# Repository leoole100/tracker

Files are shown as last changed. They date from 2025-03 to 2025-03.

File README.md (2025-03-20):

# Modular Tracking
Real-time detection, tracking, and control are fundamental to applications in robotics and automation. This project presents a modular, high-speed camera tracking system designed to explore detection, tracking, and control strategies by following a ping pong ball during gameplay. The system combines a Raspberry Pi Camera V2, stepper motors, and a Raspberry Pi 5, achieving real-time tracking at 200 fps through a modular Python-based software stack. The modular design and user-friendly interface make the system accessible for experimentation and learning, while its performance under controlled conditions demonstrates its potential for applications in robotics, sports analytics, and beyond.

Watch the video (https://youtu.be/diDA-3Ysf_I)
### [Watch this explanation on YouTube](https://youtu.be/diDA-3Ysf_I)

### Introduction

Real-time object tracking is a core challenge in computer vision and
robotics. Moving a camera to track a ping pong ball during gameplay
creates an interesting platform to explore and evaluate detection,
tracking, and control strategies. This is due to its unique combination
of steady ballistic flight interrupted by rapid, complex bounces at high
speeds.

To simplify the exploration of different strategies, the system is
designed with modularity and accessibility in mind. Each component is
built around high-level concepts, enabling users to experiment without
requiring an in-depth engineering background.

## Methods

The system is designed to track a ping pong ball in real time by moving
a camera dynamically. To achieve this, the project is broken down into
modular components, each addressing a specific aspect of the tracking
process.

### Hardware

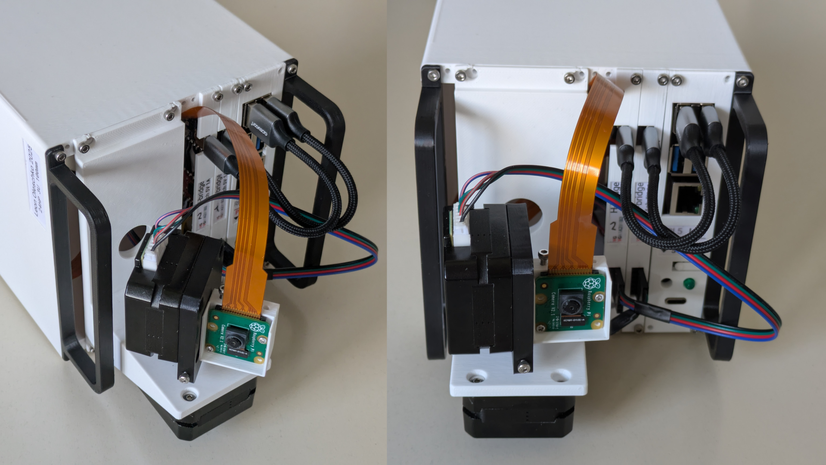
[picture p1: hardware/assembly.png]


The hardware components consists of a camera, motors, motor controllers
and a processing computer.\
The modules are designed as subrack modules and can be assembled as
shown in the figure above.

For the camera a Raspberry Pi Camera V2 is used, as with the
[picamera2](https://github.com/raspberrypi/picamera2) software stack it
supports a framerate of 200 Hz. A normal 30 Hz USB Webcam was tested to
be not sufficient.\
To move the camera 2 common stepper motors are mounted perpendicularly.
They are driven with field oriented controllers with the
[SimpleFOC](https://simplefoc.com/) firmware stack. They are connected
to the control computer using the Universal Serial Bus (USB).\
The chosen computer is a Raspberry Pi 5.

To power the components 9 V 3 A from a USB-C power supply are converted
to a 5 V 5 A bus for the computer and another 5 V 3 A bus for the
motors. Additionally the startup of the computer and the motors is
staggered. This was necessary to achieve stable operation.

### Software

The software architecture is designed to be modular, ensuring
flexibility and ease of experimentation. It is split into a camera
module, detector module, and motor module, with plans to add a tracker
module and controller module in the future. Each module can be
independently evaluated, modified, or replaced, allowing users to
experiment with different algorithms and configurations without
affecting the entire system.

The camera module configures the camera into a high frame rate mode and
fetches new frames.

The detector identifies the center of the ping pong ball in the image by
comparing each pixel's color $I(x,y)$ to a predefined reference color
$R$ in the Hue Saturation Luminance (HSL) color space. Testing showed
that HSL outperformed Luminance-AB (LAB). For each pixel, a weight $w$
is computed: $$w = \exp\left(- \frac{(I(x,y)-R)^2}{\sigma}\right)$$
Where $\sigma$ is the standard deviation of each channel in a reference
image of the ball. This function emphasizes pixels closely matching the
reference color while exponentially reducing the influence of outliers.
The color channels are then summed to get one weight for each pixel. The
location of the ball is determined by finding the position of the
maximum weight in the image.\
This process is efficiently implemented using
[numpy](https://numpy.org/), allowing the detector to process an
downsampled $80\times 60$ pixel frame in 3.6 ms. This high-speed
performance is critical for real-time tracking, ensuring the system can
keep up with the fast-moving ball during gameplay.

The tracker evaluates the detector's maximum weight $w_\text{max}$ to
determine if the detection is valid. Using hysteresis, it compares
$w_\text{max}$ to two thresholds $T_\text{heigh} > T_\text{low}$. If
$\omega_\text{max}>T_\text{heigh}$ it is valid; if
$\omega_\text{max}<T_\text{low}$ it is invalid. For values In between
$T_\text{low}<\omega_\text{max}<T_\text{heigh}$ the pervious state is
kept.\
This hysteresis-based approach ensures robust and smooth tracking, even
under challenging conditions.

The motors are moved based on the error, which is the angle between the
detected ball position and the center of the camera's field of view.
This error is scaled by a constant factor, producing a control signal
that drives the motors. This approach is known as a P-regulator
(proportional controller), where the motor response is directly
proportional to the error. While simple, this method provides effective
and responsive control for keeping the ball centered in the frame.

## Results

The simple detection and tracking approach works smoothly under
controlled lighting conditions and with a differently colored
background. However, in uncontrolled lighting environments, the
threshold for detection must be lowered to maintain sensitivity, which
introduces false positives. Despite this limitation, the system
demonstrates robust performance in ideal conditions, highlighting its
potential for applications where lighting can be managed.

## Conclusion

This project demonstrates the feasibility of a modular, high-speed
camera tracking system for following a ping pong ball in real time. By
combining a simple yet effective detection algorithm with a proportional
controller, the system achieves reliable performance under controlled
lighting conditions. The modular design allows for easy experimentation
with different strategies, making it a versatile platform for learning
and innovation in real-time object tracking.

Future work could focus on improving robustness in uncontrolled lighting
environments, such as by incorporating adaptive thresholding or machine
learning-based detection methods. Additionally, expanding the system to
include more advanced control strategies, like PID control or predictive
tracking, could further enhance performance. The platform also holds
potential for applications beyond ping pong, such as in robotics, sports
analytics, or automated surveillance, making it a valuable tool for both
education and research.

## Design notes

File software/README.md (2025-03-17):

To install requirements on raspberry pi os:
```bash
sudo apt install python3-flask-socketio python3-picamera2 python3-opencv python3-serial
```

To autostart create a system service:
```bash
sudo nano /etc/systemd/system/tacker.service
sudo systemctl enable tracker.service 
```

```
[Unit]
Description=Tracker
After=network.target

[Service]
Type=simple
ExecStart=/usr/bin/python3 /home/leon/tracker/software/main.py

[Install]
WantedBy=multi-user.target
```

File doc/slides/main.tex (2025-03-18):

\documentclass[aspectratio=169, 20pt]{beamer}
\input{preamble.tex}

\author{Leon Oleschko}
\date{\today}

\begin{document}
\begin{frame}
	\large
	\markieren{}{}{Modular Tracker}{following a ping pong ball}
	
	\vfill
	\normalsize
	Leon Oleschko\\
	\today
	
	\vfill
\end{frame}

\begin{frame}{Demo}
\end{frame}

\section{Hardware}
\slidefigure{../../figures/usb_webcam.png}
\slidefigure{../../figures/rpicam.png}
\slidefigure{../../figures/stepper.png}
\slidefigure{../../figures/stepper_mounted.png}
\slidefigure{../../figures/driver.png}
\slidefigure{../../figures/computer.png}
\slidefigure{../../figures/assembly.png}

\section{Software}
\slidefigure{../../figures/ball.png}
\begin{frame}
	\begin{gather*}
		\adjincludegraphics[height=3.5cm, valign=c]{../../figures/ball.png}
		= \\
		\adjincludegraphics[height=4cm, valign=c]{../../figures/rgb.png}
	\end{gather*}
\end{frame}

\begin{frame}
	\begin{align*}
		&\adjincludegraphics[height=3.5cm, valign=c]{../../figures/rgb.png}\\
		\Rightarrow\; &\adjincludegraphics[height=3.5cm, valign=c]{../../figures/hsv.png}
	\end{align*}
\end{frame}

\begin{frame}
	\begin{gather*}
		- \left(
				\adjincludegraphics[height=2cm, valign=c]{../../figures/hsv.png} - \adjincludegraphics[height=2cm, valign=c]{../../figures/mean.png}
		\right)^2\\
	= \adjincludegraphics[height=3cm, valign=c]{../../figures/diff.png}
	\end{gather*}
\end{frame}

\begin{frame}
	\begin{gather*}
		- \left|
			\frac{
				\adjincludegraphics[height=2cm, valign=c]{../../figures/diff.png}
			}{(\sigma_H, \sigma_S, \sigma_V)}
		\right|^2
	= \adjincludegraphics[height=4cm, valign=c]{../../figures/weight.png}
	\end{gather*}
\end{frame}

\begin{frame}
\end{frame}
\end{document}

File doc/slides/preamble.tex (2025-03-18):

\setbeamertemplate{navigation symbols}{}
\usepackage{xcolor}
\definecolor{seeblau}{HTML}{00A9E0}
\definecolor{seegrau}{HTML}{9AA0A7}

\definecolor{seeblau1}{HTML}{CCEEF9}
\definecolor{seeblau2}{HTML}{A6E1F4}
\definecolor{seeblau3}{HTML}{59C7EB}
\definecolor{seeblau4}{HTML}{00A9E0}
\definecolor{seeblau5}{HTML}{008ECE}

\setbeamercolor{title}{fg=seeblau}
\setbeamercolor{frametitle}{fg=seeblau}
\setbeamercolor{section in toc}{fg=seeblau}
\setbeamercolor{structure}{fg=seeblau}

\setbeamertemplate{footline}{%
	\begin{beamercolorbox}[sep=.25cm,wd=\paperwidth,leftskip=0.25cm,rightskip=0.25cm]{footlinecolor}
		\small
		% \textbf{\insertsection}\quad\insertsubsection
		% \hfill\insertframenumber
	\end{beamercolorbox}%
}

\usepackage[overridenote]{pdfpc}

\usepackage[english]{babel}
\parskip=20pt

\usepackage[sfdefault]{roboto}
\usepackage{libertinust1math}
\usefonttheme[onlymath]{serif}

\usepackage{ifthen, adjustbox}
\newcommand{\markieren}[4]{
	\ifthenelse{\equal{#1}{}}{}{\adjustbox{padding=3pt, bgcolor=seeblau1, margin=-1pt}{\strut{\sffamily\robotoMedium{#1}}}\\}
  \ifthenelse{\equal{#2}{}}{}{\adjustbox{padding=3pt, bgcolor=seeblau2, margin=-1pt}{\strut{\sffamily\robotoMedium{#2}}}\\}
	\ifthenelse{\equal{#3}{}}{}{\adjustbox{padding=3pt, bgcolor=seeblau3, margin=-1pt}{\strut{\sffamily\robotoMedium{#3}}}\\}
	\ifthenelse{\equal{#4}{}}{}{\adjustbox{padding=3pt, bgcolor=seeblau4, margin=-1pt}{\strut{\sffamily\robotoMedium{#4}}}}
}

\let\footnoterule\relax % removes bar
\setbeamertemplate{footnote}{
  \parindent 0em\noindent
  \raggedleft
  \usebeamercolor{footnote}\hbox to 0.8em{\hfil\insertfootnotemark}\tiny\insertfootnotetext\par%
}

\newcommand\blfootnote[1]{
	\let\thefootnote\relax\footnotetext{#1}
}

\usepackage[
	style=authortitle
]{biblatex}
\usepackage{ifthen}
\newcommand{\customcite}[2][]{
	\blfootnote{
		\emph{\citetitle{#2}}, \citeauthor*{#2}	\citeyear{#2}
		\ifthenelse{ \equal{#1}{} }{}{(#1)}
	}
}

\newcommand{\highlightcite}[2][]{
	\blfootnote{
		\color{seeblau}
		\small
		\emph{\citetitle{#2}}, \citeauthor*{#2}	\citeyear{#2}
		\ifthenelse{ \equal{#1}{} }{}{(#1)}
	}
}

\usepackage[ddmmyyyy]{datetime}
\renewcommand{\dateseparator}{.}

\usepackage{amsmath,amssymb,amsfonts,amsthm}

\usepackage{tikz}

\newcommand{\slidefigure}[1]{
{ % all template changes are local to this group.
\setbeamertemplate{navigation symbols}{}
\begin{frame}<article:0>[plain]
	\begin{tikzpicture}[remember picture,overlay]
		\node[at=(current page.center)] {
			\includegraphics[keepaspectratio,
								width=\paperwidth,
								height=\paperheight]{#1}
		};
	\end{tikzpicture}
	\end{frame}
}
}

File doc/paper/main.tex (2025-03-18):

\documentclass[
    parskip=half, 
    twoside=false,
    twocolumn=true,
    fontsize=12pt,
]{scrarticle}
\input{preamble.tex}

\begin{document}

\title{Modular Tracking}
\author{Leon Oleschko}
\date{\dotdate\today}

\twocolumn[{%
    \sffamily
    \huge
    \markieren{}{}{Modular Tracker}{following a ping pong ball}
    \vspace{.5 cm}\\
    \normalsize
    Leon Oleschko\\
    \dotdate\today
    \vspace{.5 cm}\\
    \normalfont
    \begin{abstract}
        Real-time detection, tracking, and control are fundamental to applications in robotics and automation. This project presents a modular, high-speed camera tracking system designed to explore detection, tracking, and control strategies by following a ping pong ball during gameplay. The system combines a Raspberry Pi Camera V2, stepper motors, and a Raspberry Pi 5, achieving real-time tracking at \SI{200}{Hz} through a modular Python-based software stack. The modular design and user-friendly interface make the system accessible for experimentation and learning, while its performance under controlled conditions demonstrates its potential for applications in robotics, sports analytics, and beyond.
    \end{abstract}
    \bigskip
}]

\subsection*{Introduction}
Real-time object tracking is a core challenge in computer vision and robotics. Moving a camera to track a ping pong ball during gameplay creates an interesting platform to explore and evaluate detection, tracking, and control strategies. This is due to its unique combination of steady ballistic flight interrupted by rapid, complex bounces at high speeds.

To simplify the exploration of different strategies, the system is designed with modularity and accessibility in mind. Each component is built around high-level concepts, enabling users to experiment without requiring an in-depth engineering background.

\section{Methods}
The system is designed to track a ping pong ball in real time by moving a camera dynamically. To achieve this, the project is broken down into modular components, each addressing a specific aspect of the tracking process. 

\subsection*{Hardware}
\begin{figure}
    \centering
    
    \caption{Mechanical assembly of all components.}
    \label{fig:assembly}
\end{figure}
The hardware components consists of a camera, motors, motor controllers and a processing computer.\\
The modules are designed as subrack modules and can be assembled as shown in \autoref{fig:assembly}.

For the camera a Raspberry Pi Camera V2 is used, as with the \href{https://github.com/raspberrypi/picamera2}{picamera2} software stack it supports a framerate of \SI{200}{Hz}.
A normal \SI{30}{Hz} USB Webcam was tested to be not sufficient.\\
To move the camera 2 common stepper motors are mounted perpendicularly.
They are driven with field oriented controllers with the \href{https://simplefoc.com/}{SimpleFOC} firmware stack.
They are connected to the control computer using the Universal Serial Bus (USB).\\
The chosen computer is a Raspberry Pi 5.

To power the components \SI{9}{V}~\SI{3}{A} from a USB-C power supply are converted to a \SI{5}{V}~\SI{5}{A} bus for the computer and another \SI{5}{V}~\SI{3}{A} bus for the motors.
Additionally the startup of the computer and the motors is staggered.
This was necessary to achieve stable operation.

\subsection*{Software}
The software architecture is designed to be modular, ensuring flexibility and ease of experimentation. It is split into a camera module, detector module, and motor module, with plans to add a tracker module and controller module in the future. Each module can be independently evaluated, modified, or replaced, allowing users to experiment with different algorithms and configurations without affecting the entire system.

The camera module configures the camera into a high frame rate mode and fetches new frames.

The detector identifies the center of the ping pong ball in the image by comparing each pixel's color $I(x,y)$ to a predefined reference color $R$ in the Hue Saturation Luminance (HSL) color space.
Testing showed that HSL outperformed Luminance-AB (LAB).
For each pixel, a weight $w$ is computed:
$$w = \exp\left(- \frac{(I(x,y)-R)^2}{\sigma}\right)$$
Where $\sigma$ is the standard deviation of each channel in a reference image of the ball.
This function emphasizes pixels closely matching the reference color while exponentially reducing the influence of outliers.
The color channels are then summed to get one weight for each pixel.
The location of the ball is determined by finding the position of the maximum weight in the image.\\
This process is efficiently implemented using \href{https://numpy.org/}{numpy}, allowing the detector to process an downsampled $80\times 60$ pixel frame in \SI{3.6}{ms}.
This high-speed performance is critical for real-time tracking, ensuring the system can keep up with the fast-moving ball during gameplay.

The tracker evaluates the detector's maximum weight $w_\text{max}$ to determine if the detection is valid.
Using hysteresis, it compares $w_\text{max}$ to two thresholds $T_\text{heigh} > T_\text{low}$.
If $\omega_\text{max}>T_\text{heigh}$ it is valid; if $\omega_\text{max}<T_\text{low}$ it is invalid.
For values In between $T_\text{low}<\omega_\text{max}<T_\text{heigh}$ the pervious state is kept.\\
This hysteresis-based approach ensures robust and smooth tracking, even under challenging conditions. 

The motors are moved based on the error, which is the angle between the detected ball position and the center of the camera's field of view. This error is scaled by a constant factor, producing a control signal that drives the motors. This approach is known as a P-regulator (proportional controller), where the motor response is directly proportional to the error. While simple, this method provides effective and responsive control for keeping the ball centered in the frame.

\section{Results}
The simple detection and tracking approach works smoothly under controlled lighting conditions and with a differently colored background. However, in uncontrolled lighting environments, the threshold for detection must be lowered to maintain sensitivity, which introduces false positives. Despite this limitation, the system demonstrates robust performance in ideal conditions, highlighting its potential for applications where lighting can be managed.

\section{Conclusion}
This project demonstrates the feasibility of a modular, high-speed camera tracking system for following a ping pong ball in real time. By combining a simple yet effective detection algorithm with a proportional controller, the system achieves reliable performance under controlled lighting conditions. The modular design allows for easy experimentation with different strategies, making it a versatile platform for learning and innovation in real-time object tracking.

Future work could focus on improving robustness in uncontrolled lighting environments, such as by incorporating adaptive thresholding or machine learning-based detection methods. Additionally, expanding the system to include more advanced control strategies, like PID control or predictive tracking, could further enhance performance. The platform also holds potential for applications beyond ping pong, such as in robotics, sports analytics, or automated surveillance, making it a valuable tool for both education and research.

\end{document}

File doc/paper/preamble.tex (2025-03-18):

\usepackage{xcolor}
\definecolor{seeblau}{HTML}{00A9E0}
\definecolor{seegrau}{HTML}{9AA0A7}

\definecolor{seeblau1}{HTML}{CCEEF9}
\definecolor{seeblau2}{HTML}{A6E1F4}
\definecolor{seeblau3}{HTML}{59C7EB}
\definecolor{seeblau4}{HTML}{00A9E0}
\definecolor{seeblau5}{HTML}{008ECE}

\usepackage{graphicx}
\usepackage{amsmath}
\usepackage{subcaption}
\usepackage{wrapfig}
\usepackage[english]{babel}
\usepackage{blindtext}
\usepackage{microtype}
\usepackage{siunitx}
\usepackage[utf8]{inputenc}
\usepackage{csquotes}
\usepackage{nicefrac}
\usepackage[T1]{fontenc}
\usepackage{amsfonts}
\usepackage{amssymb}
\usepackage{tikz}
\usepackage{parskip}

\usepackage{libertinus, libertinust1math}
\usepackage[sfdefault]{biolinum}
\usepackage{roboto}

\setkomafont{disposition}{\normalfont\sffamily}

% set margins
\usepackage{geometry}
\geometry{
	a4paper,
	left=2.5cm,
	right=2.5cm,
	top=2.5cm,
	bottom=2.5cm
}

% not recommended with KOMA-script
% make table of contents sans-serif
% \usepackage{tocloft}
% \renewcommand\cftchappagefont{\normalfont}
% \renewcommand\cftchapfont{\normalfont}
% \renewcommand\cftchappresnum{\bfseries}
% \renewcommand\cftchapaftersnum{}
% \renewcommand{\cftchapfont}{\sffamily}
% \renewcommand{\cftsecfont}{\sffamily}
% \renewcommand{\cftsubsecfont}{\sffamily}
% \renewcommand{\cftchappagefont}{\sffamily}
% \renewcommand{\cftsecpagefont}{\sffamily}
% \renewcommand{\cftsubsecpagefont}{\sffamily}

% caption
\usepackage{caption}
\captionsetup{
	% font={sf},
	labelfont={sf, bf, color=seeblau},
	labelsep=quad,
	labelformat=simple,
}

% links
\usepackage{hyperref}
\hypersetup{
	colorlinks=true,
	linkcolor=seeblau,
	citecolor=seeblau,
	urlcolor=seeblau,
	% hidelinks=true
}

% bibliography
\usepackage[
	style=numeric-comp, % comp = compressed 4,5,6,7 -> 4-7
	sorting=none,		% Sort by appearance
	% autocite = superscript,
	% backref=true,
	hyperref=true,
	url=true,
	maxbibnames=100
]{biblatex}

\usepackage{float}
% \floatplacement{figure}{h}
% \floatplacement{table}{H}

% loosen float placement rules
\renewcommand{\topfraction}{0.8}
\renewcommand{\bottomfraction}{.8}
\renewcommand{\textfraction}{0.1}
\renewcommand{\floatpagefraction}{.9}
% make floats less likely to be placed on a separate page
\setcounter{totalnumber}{9}
\setcounter{topnumber}{9}
\setcounter{bottomnumber}{9}

% decrease space between floats and text
\setlength{\textfloatsep}{0.25cm}
\setlength{\floatsep}{0.25cm}

% decrease space after disposition
\RedeclareSectionCommands[
	afterskip=1px
]{section, subsection, subsubsection}

\usepackage{adjustbox}

\usepackage{datetime}
\newdateformat{dotdate}{
	\twodigit{\THEDAY}.\twodigit{\THEMONTH}.\THEYEAR
}
\newdateformat{monthyeardate}{%
  \monthname[\THEMONTH] \THEYEAR}

% header and footer
\usepackage[
  markcase=noupper
]{scrlayer-scrpage}% activates pagestyle scrheadings automatically
\clearpairofpagestyles
\setkomafont{pageheadfoot}{\normalfont\sffamily}
\setkomafont{pagenumber}{\normalfont\sffamily}
% \chead*{\color{seegrau} Draft \dotdate\today}
\ofoot*{\pagemark}
\ohead*{\rightmark}

\usepackage{ifthen, adjustbox}
\newcommand{\markieren}[4]{
	\ifthenelse{\equal{#1}{}}{}{\adjustbox{padding=3pt, bgcolor=seeblau1, margin=-1pt}{\strut{\sffamily\robotoMedium{#1}}}\\}
  \ifthenelse{\equal{#2}{}}{}{\adjustbox{padding=3pt, bgcolor=seeblau2, margin=-1pt}{\strut{\sffamily\robotoMedium{#2}}}\\}
	\ifthenelse{\equal{#3}{}}{}{\adjustbox{padding=3pt, bgcolor=seeblau3, margin=-1pt}{\strut{\sffamily\robotoMedium{#3}}}\\}
	\ifthenelse{\equal{#4}{}}{}{\adjustbox{padding=3pt, bgcolor=seeblau4, margin=-1pt}{\strut{\sffamily\robotoMedium{#4}}}}
}

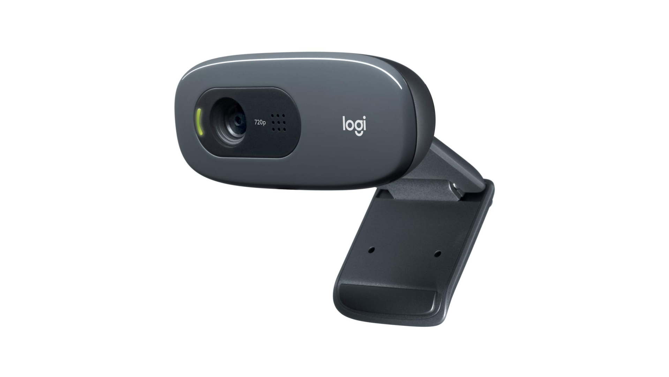
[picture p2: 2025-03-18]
figures/usb_webcam.png

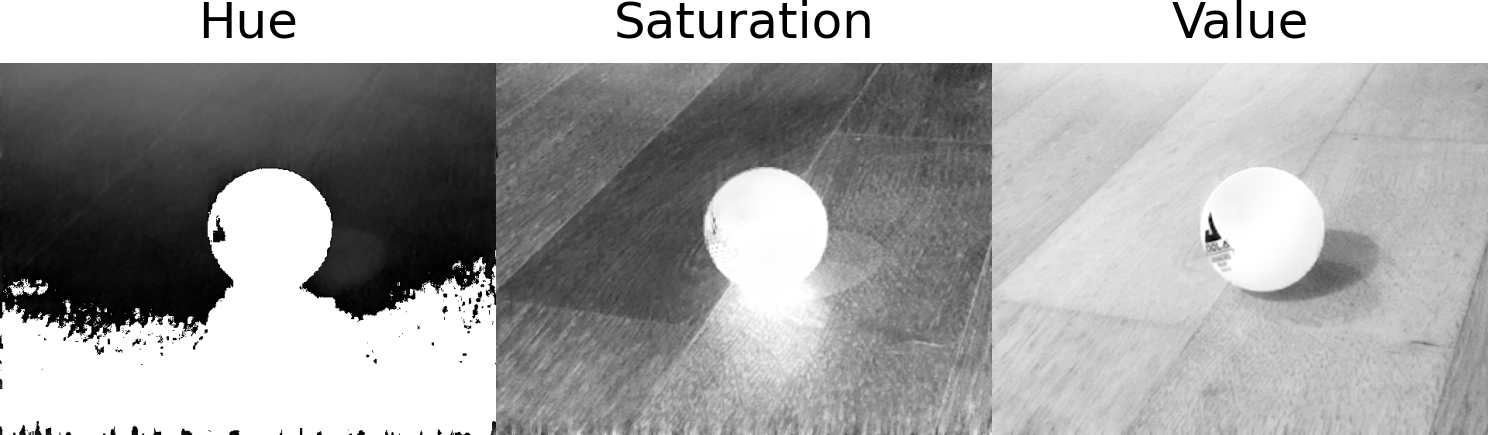
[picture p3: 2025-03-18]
figures/diff.png

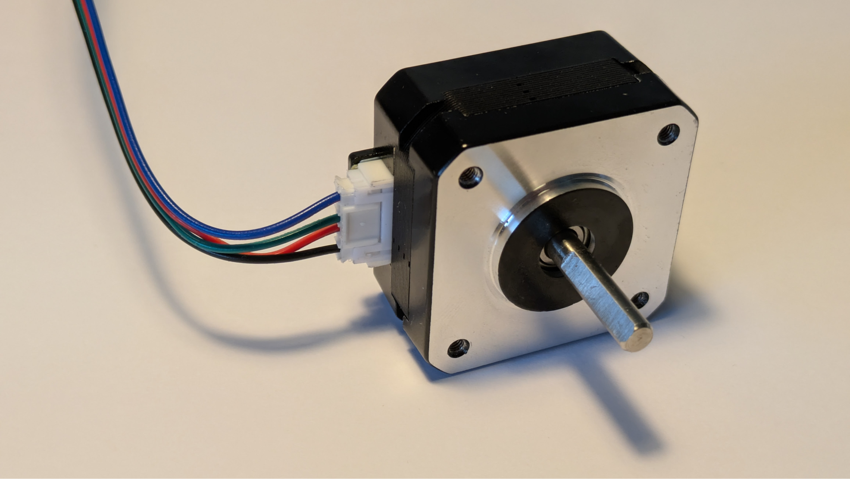
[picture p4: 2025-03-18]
figures/stepper.png

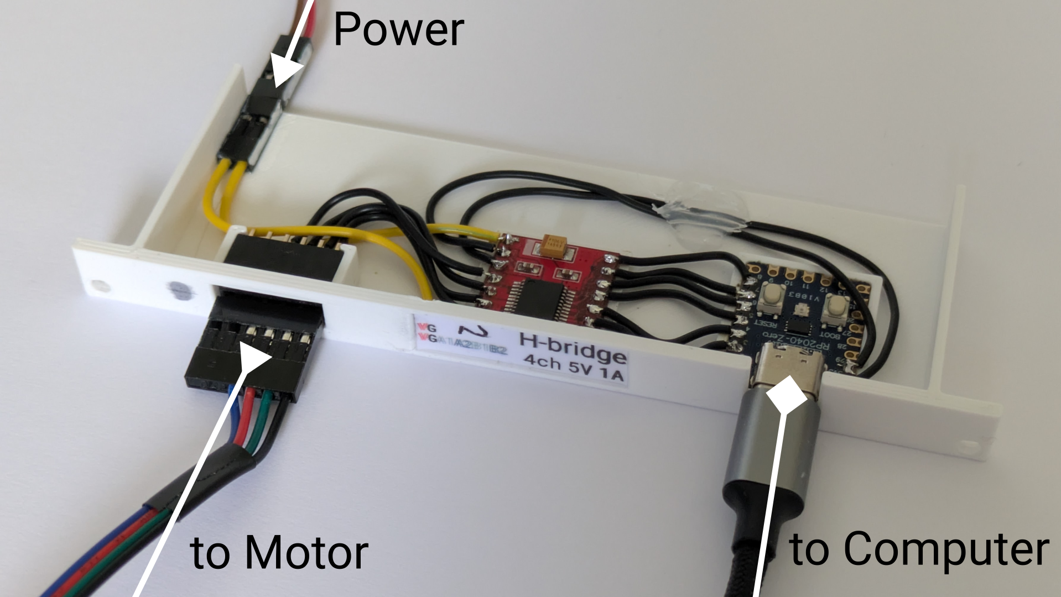
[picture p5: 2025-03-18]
figures/driver.png

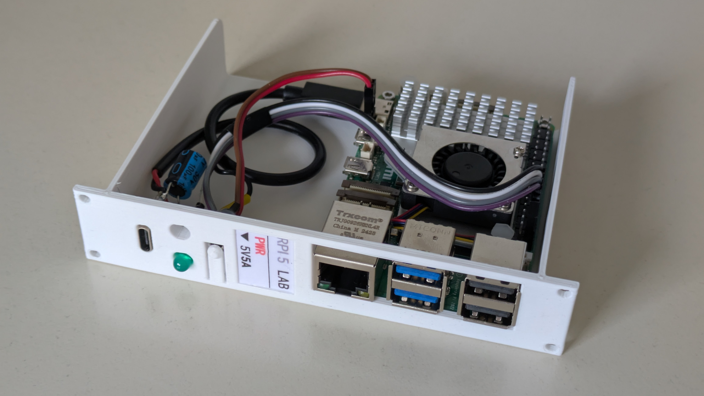
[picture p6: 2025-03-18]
figures/computer.png

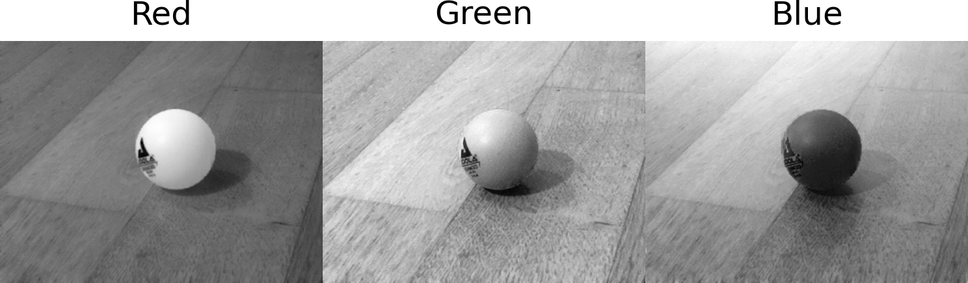
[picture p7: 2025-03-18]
figures/rgb.png

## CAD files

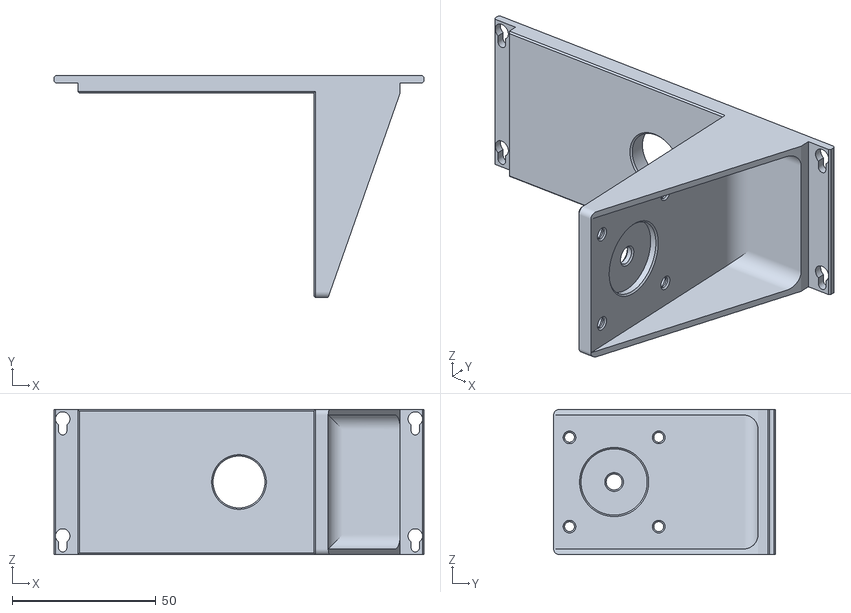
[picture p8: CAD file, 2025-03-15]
hardware/base-Body.stl
128.6 x 77.0 x 50.5

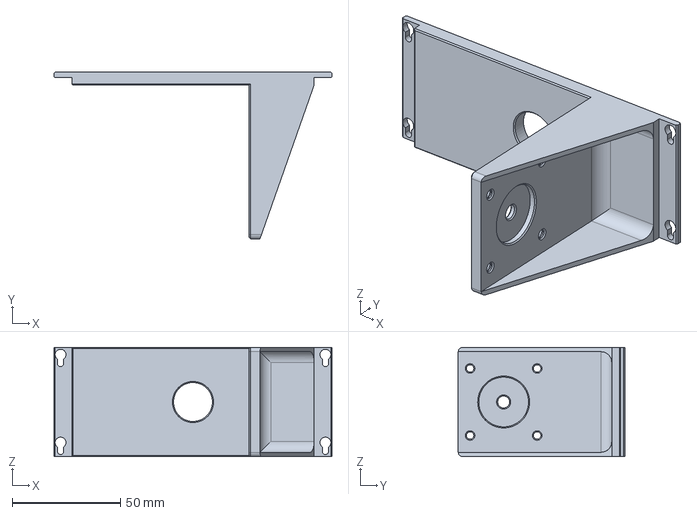
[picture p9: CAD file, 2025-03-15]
hardware/base.FCStd
128.6 x 77.0 x 50.5 mm

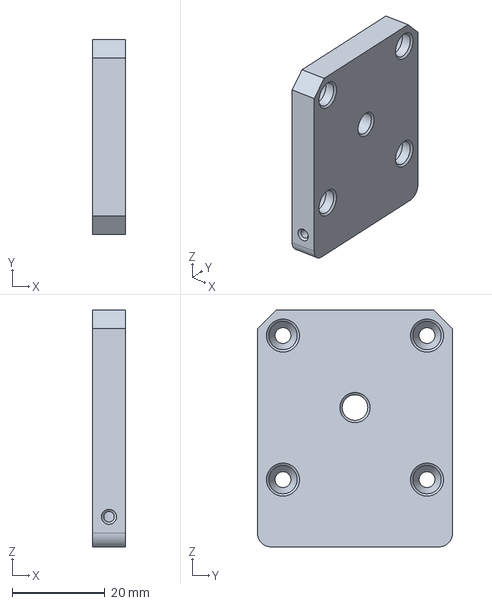
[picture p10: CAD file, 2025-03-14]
hardware/angle.FCStd
7.00 x 42.0 x 51.0 mm

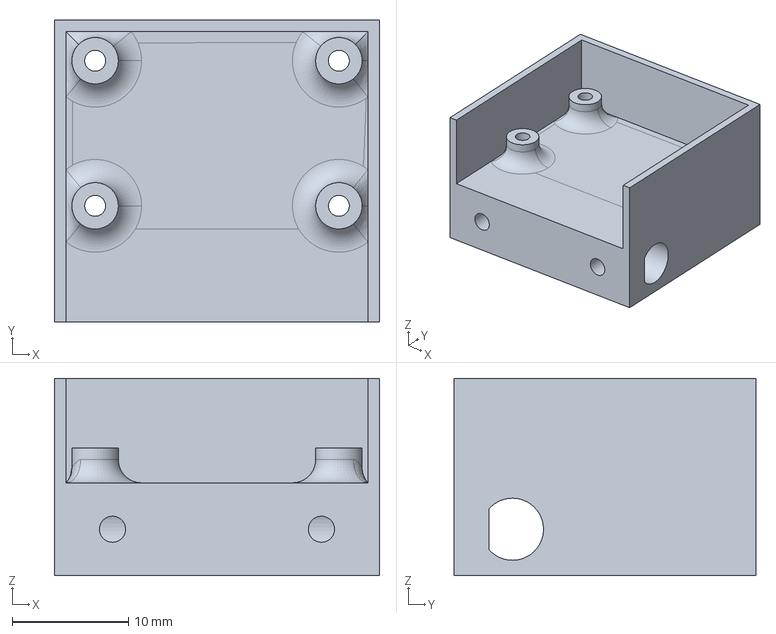
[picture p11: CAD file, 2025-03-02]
hardware/camera_holder.FCStd
28.0 x 26.0 x 17.0 mm

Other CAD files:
hardware/angle-Body.stl
hardware/camera_holder-BodyFillet.stl

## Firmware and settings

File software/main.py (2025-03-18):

#%%
from tools import *
import numpy as np
from math import pi, cos
import json
from flask import Flask, render_template, Response, send_from_directory
from flask_socketio import SocketIO
import cv2

from camera import Camera
cam = Camera()
time.sleep(1)

from detector import Detector
det = Detector()

from motor import Motor
 
m2 = Motor("/dev/serial/by-id/usb-Raspberry_Pi_Pico_504450612038C51C-if00")
m1 = Motor("/dev/serial/by-id/usb-Waveshare_RP2040_Zero_504450612862EA1C-if00")

# web server
app = Flask(__name__)
socketio = SocketIO(app)

import logging
log = logging.getLogger('werkzeug')
log.setLevel(logging.ERROR)

# %%
scale = 0.415
f = cam()
dg = det(f)
p = 0.25
threshold = -20
hysteresis = 30
last = time.time()
tracking = False

pos = np.array([pi, pi])
m1(pos[0])
m2(pos[1])
time.sleep(0.2)
# overpower the axis to be perpendicular


def loop():
    global f, dg, p, pos, last, tracking, hysteresis, det
    f = cam()
    d = det(f)
    if (tracking and d["signal"] > threshold-hysteresis) or (not tracking and d["signal"] > threshold):
        tracking = True
        error = (d["center"]-np.array([0.5, 0.5]))*scale*[4/3, 1]
        pos[0] += p*error[0]
        m1(pos[0])
        pos[1] -= p*error[1] * - cos(pos[0])
        m2(pos[1])
    else: tracking = False
    td = time.time() - last
    last = time.time()
    dg = {
        **d,
        "tracking": tracking,
        "time": td,
        "threshold": threshold,
        "hysteresis": hysteresis,
        "p": p,
        "scale": det.scale
    }
    socketio.emit("data", json.dumps(dg))

loop()

from threading import Thread
running = True
def tracking_task():
    global running
    while running:
        loop()

# %%
tracking_thread = Thread(target=tracking_task)
tracking_thread.start()

# %%
# https://github.com/log0/video_streaming_with_flask_example
def gen():
    global f
    while True:
        ret, buf = cv2.imencode(".jpg", f[...,::-1])
        yield (b'--frame\r\n'
               b'Content-Type: image/jpeg\r\n\r\n' + buf.tobytes() + b'\r\n\r\n')
        time.sleep(1/30)

@app.route('/')
def index():
        return send_from_directory('static/', "index.html")

@app.route('/<path:path>')
def sendstuff(path):
    return send_from_directory('static/', path, max_age=0)

@app.route('/video_feed')
def video_feed():
    return Response(gen(),
                    mimetype='multipart/x-mixed-replace; boundary=frame')

@socketio.on("setting")
def on_setting(data):
    global threshold, hysteresis, p, det
    data = json.loads(data)
    print(data)
    if "threshold" in data:
        threshold = float(data["threshold"])
    if "hysteresis" in data:
        hysteresis = float(data["hysteresis"])
    if "p" in data:
        p = float(data["p"])
    if "scale" in data:
        det.scale = float(data["scale"])

@socketio.on("home")
def on_setting(data):
    global pos
    pos = np.array([pi, pi])
    m1(pos[0])
    m2(pos[1])
    
print("starting server")
socketio.run(app, host='0.0.0.0', port=8080, allow_unsafe_werkzeug=True)
# %%

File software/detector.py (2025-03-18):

# %%
import numpy as np
import numpy as np
import cv2
import math
from glob import glob
import os

def log10_clamp(a):
	if a<=0: return -9999999999
	return math.log10(a)

class Detector():
	# size = (160, 120)
	size = (80, 60)
	def __init__(self):
		os.chdir(os.path.dirname(__file__))
		templates = [cv2.imread(p) for p in glob("*.png")]
		templates_lab = [cv2.cvtColor(i, cv2.COLOR_BGR2HSV) for i in templates]
		lab = np.concatenate([t.reshape(t.shape[0]*t.shape[1], 3) for t in templates_lab])
		self.mean = np.mean(lab, axis=0)
		self.std = np.std(lab, axis=0)
		self.scale = 2.

	# 3.6 ms
	def __call__(self, f):
		self.f_small = cv2.resize(f, self.size)
		self.fc = cv2.cvtColor(self.f_small, cv2.COLOR_RGB2HSV)
		self.diff = self.fc - self.mean
		self.w = -np.mean(self.diff**2 /(self.scale*self.std), axis=2)
		# self.w = np.exp(self.w)
		amax = np.unravel_index(self.w.argmax(), self.w.shape)
		# signal = log10_clamp(self.w[amax])*10
		signal = self.w[amax]
		# snr = log10_clamp(signal/np.mean(self.w))*10
		return {
      		"center": (np.array(amax)/np.array(self.w.shape))[::-1].tolist(),
			"signal": signal,
			# "snr": snr
		}

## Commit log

2025-03-01 implemented a kalman filter
2025-03-02 added rpi camera
2025-03-02 added hardware
    [camera_holder-BodyFillet.stl, camera_holder.FCStd]
2025-03-12 added 100fps camera script
2025-03-13 single threaded python app
2025-03-14 working but slow implementation
    [angle-Body.stl, angle.FCStd]
2025-03-15 changes to hardware
    [base-Body.stl, base.FCStd]
